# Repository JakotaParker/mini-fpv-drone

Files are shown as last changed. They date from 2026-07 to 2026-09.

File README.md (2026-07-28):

# Mini 3-Inch FPV Drone

A documented engineering project to design, manufacture, assemble, configure, and test a mini 3-inch FPV quadcopter with a primarily 3D-printed airframe.

## Current Project Status

**Phase:** Step 1 — Define the Project  
**Current revision:** Frame V1  
**Frame status:** CAD model completed in Onshape  
**Manufacturing status:** Full Frame V1 print has not yet been completed and validated  
**Flight status:** Not assembled or flight-tested  

Frame V1 must be treated as an **unvalidated prototype** until it passes dimensional inspection, component-fit checks, structural checks, and a complete print test.

## Primary Objectives

- Design a functional 3-inch FPV quadcopter.
- Use an Ender 3 V2 to prototype the frame.
- Learn CAD design, additive manufacturing, electronics integration, soldering, Betaflight configuration, and flight testing.
- Maintain professional engineering documentation throughout the build.
- Create a platform that can later support more advanced embedded-systems and autonomous-drone projects.

## Initial System Architecture

```mermaid
flowchart TD
    Pilot[Pilot] --> Radio[Radio Transmitter]
    Radio --> RX[ELRS Receiver]
    RX --> FC[Flight Controller]
    FC --> ESC[Electronic Speed Controllers]
    ESC --> Motors[Four Brushless Motors]
    Battery[LiPo Battery] --> ESC
    Battery --> FC
    FC --> VTX[Video Transmitter]
    Camera[FPV Camera] --> VTX
    VTX --> Goggles[FPV Goggles]
    Frame[3D-Printed Frame] --> Motors
    Frame --> FC
    Frame --> Battery
    Frame --> Camera
```

## Repository Structure

- `docs/` — project definition, requirements, architecture, BOM, build log, and test plan
- `cad/` — exported CAD revisions, drawings, screenshots, and Onshape links
- `electronics/` — wiring diagrams, pin maps, and electronics integration notes
- `firmware/` — Betaflight configuration backups and firmware notes
- `manufacturing/` — slicer settings, print profiles, and manufacturing observations
- `tests/` — dimensional, structural, electronics, bench, and flight-test records
- `media/` — labeled photos and videos used in the documentation

## Versioning Rules

- Use `Frame V1`, `Frame V2`, and so on for major geometry revisions.
- Never overwrite an old validated or tested design.
- Record the reason for every revision in `CHANGELOG.md`.
- Export both `.STL` and `.STEP` when a CAD revision is ready for review.
- Use filenames such as:
  - `frame-v1.stl`
  - `frame-v1.step`
  - `frame-v1-top.png`
  - `frame-v1-print-test-2026-07-22.md`

# Current Project Status

## Completed

- Initial project planning
- System architecture
- Custom Frame V1
- Mini prototype printed
- Component compatibility verification
- Final BOM selected
- All components ordered

## Current Phase

Mechanical Integration (Frame V2)

## Next Milestones

- Receive components
- Measure actual dimensions
- Update Onshape
- Print Frame V2
- Assemble electronics
- First power-on
- Configure Betaflight
- Maiden hover

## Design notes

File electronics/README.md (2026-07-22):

# Electronics

Store the electrical architecture and wiring documentation here.

## Planned Files

- `wiring-diagram.md`
- `flight-controller-pin-map.md`
- `power-budget.md`
- `soldering-checklist.md`
- `continuity-test-log.md`

## Safety Rule

Do not install propellers during soldering, continuity testing, firmware configuration, receiver setup, or motor-direction testing.

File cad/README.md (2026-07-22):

# CAD Directory

Store exported design files by revision. Onshape remains the cloud CAD source of truth, while GitHub stores reviewable exports and revision documentation.

## Recommended Revision Structure

- `frame-v1/`
- `frame-v2/`
- `camera-mount-v1/`
- `antenna-mount-v1/`

Each revision folder should contain:

- Onshape link
- STL export
- STEP export
- Screenshots
- Critical dimensions
- Known issues
- Test status

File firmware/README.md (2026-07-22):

# Firmware

Use this directory for Betaflight configuration records.

## Save

- Flight-controller target and firmware version
- Date flashed
- Port configuration
- Receiver protocol
- Modes
- Motor protocol
- Motor order and direction
- Failsafe settings
- OSD settings
- VTX table
- CLI backups

## Suggested Filenames

- `betaflight-backup-before-setup-YYYY-MM-DD.txt`
- `betaflight-backup-first-hover-YYYY-MM-DD.txt`
- `betaflight-settings.md`

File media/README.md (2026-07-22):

# Media

Store compressed, labeled documentation images here.

## Naming Examples

- `2026-07-22-frame-v1-onshape-isometric.png`
- `2026-07-25-frame-v1-print-failure.jpg`
- `2026-07-27-frame-v1-motor-fit.jpg`

Avoid committing large raw videos directly to GitHub. Upload large videos elsewhere and add a link in the relevant build-log or test file.

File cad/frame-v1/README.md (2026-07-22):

# Frame V1

## Status

**CAD complete — full print not yet validated**

## Onshape Document

Paste the share link here:

`https://cad.onshape.com/documents/b07e0402ccf89ec4abb02c89/w/8f168de043c1d81def7e68bb/e/86ea48fc1ecbca987625806d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`

Use a view-only public or appropriately shared link. Do not expose private account information.

## Expected Files

- `frame-v1.stl` 
- `frame-v1.step`
- `frame-v1-top.png`
- `frame-v1-bottom.png`
- `frame-v1-isometric.png`

## Design Intent

Frame V1 is the first physical prototype for a mini 3-inch FPV quadcopter. It is intended to validate:

- Overall geometry
- Printability
- Arm stiffness
- Motor mounting
- Electronics mounting
- Camera placement
- Battery placement
- Propeller clearance
- Wiring access

## Validation Status

| Check | Status | Notes |
|---|---|---|
| CAD geometry completed | COMPLETE | Onshape model exists |
| STL exported | COMPLETE | |
| STEP exported | COMPLETE | |
| Full print completed | Not tested | |
| Dimensions measured | Not tested | |
| Motor fit checked | Not tested | |
| Electronics fit checked | Not tested | |
| Propeller clearance checked | Not tested | |
| Structural test completed | Not tested | |
| Flight tested | Not tested | |

## Known Risks

- PLA+ may be adequate for fit testing but may not be the final flight material.
- Mounting dimensions have not yet been physically validated.
- Arm stiffness and crash durability are unknown.
- Long print duration requires active supervision and printer-safety precautions.

## Frame V1 Specifications

- Propeller class: 3 inch
- Overall Length:
- Overall Width:
- Frame Thickness:
- Arm Width:
- Motor mounting-hole spacing:
- Flight-controller mounting-hole spacing:
- Estimated frame weight:
- Battery mounting location:
- Camera mounting location:

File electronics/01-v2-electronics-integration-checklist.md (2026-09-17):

# V2 Drone — Electronics Integration Checklist

Use this checklist to guide the V2 drone from completed frame to first powered flight.

---

## Phase 1 — Electronics Planning

- [x] Create an electronics assembly sequence before soldering anything
- [x] Review the exact SpeedyBee F405 AIO wiring and pad diagram
- [x] Identify the connection point for each subsystem:
  - [x] Motor 1
  - [x] Motor 2
  - [x] Motor 3
  - [x] Motor 4
  - [x] Battery / XT30
  - [x] Capacitor
  - [x] Receiver
  - [x] FPV camera
  - [x] TX800 VTX
  - [ ] Buzzer, if used
- [x] Identify the required power rails and signals:
  - [x] VBAT
  - [x] 5V
  - [x] Ground
  - [x] UART TX
  - [x] UART RX
  - [x] Video signal
  - [x] Motor phases
- [x] Create the complete electrical wiring diagram
- [x] Label every wire and destination pad
- [x] Create a physical wire-routing plan for the V2 frame
- [x] Decide the electronics stack / component placement order
- [ ] Confirm USB access after the AIO is installed
- [ ] Confirm planned wire paths cannot reach the propellers
- [ ] Save the wiring diagram to the GitHub repository

---

## Phase 2 — Parts Arrival and Unboxing

### Documentation Setup

- [x] Set up camera / Meta glasses before opening packages
- [X] Record all packages together
- [x] Record the unboxing of each major component
- [x] Capture close-up footage of each electronic component
- [x] Capture the V2 frame beside the real components
- [x] Photograph component labels, model numbers, and connectors

### Initial Inspection

- [X] Inspect every package for shipping damage
- [x] Confirm each received component matches the ordered model
- [x] Confirm all expected accessories and cables are included
- [x] Do not solder anything yet

---

## Phase 3 — Physical Component Verification

Measure every component with digital calipers and compare the measurements against the CAD envelopes and manufacturer specifications.

### Motors

- [x] Measure motor diameter
- [x] Measure motor height
- [x] Measure shaft diameter
- [x] Measure mounting-hole spacing
- [x] Verify mounting screw size
- [x] Verify motor screws do not extend into the motor windings

### SpeedyBee F405 AIO

- [x] Measure board length
- [x] Measure board width
- [x] Measure board thickness / installed height
- [x] Measure mounting-hole spacing
- [x] Measure mounting-hole diameter
- [x] Verify USB connector location
- [x] Verify battery pads
- [x] Verify motor pads
- [x] Verify UART pads
- [x] Verify video pads

### RunCam Nano 4

- [x] Measure camera width
- [x] Measure camera height
- [x] Measure camera depth
- [x] Verify cable exit direction
- [x] Verify lens clearance

### SpeedyBee TX800 VTX

- [x] Measure board length
- [x] Measure board width
- [x] Measure board thickness
- [x] Verify antenna connector orientation
- [x] Verify power / signal connection locations

### Receiver

- [x] Measure receiver length
- [x] Measure receiver width
- [x] Measure receiver thickness
- [x] Verify antenna arrangement
- [x] Verify wire / pad orientation

### Battery

- [x] Measure battery length
- [x] Measure battery width
- [x] Measure battery height
- [x] Measure battery weight
- [x] Verify XT30 lead length
- [x] Verify battery orientation in the frame

### Other Components

- [x] Verify propeller diameter
- [x] Verify propeller shaft / mounting interface
- [x] Measure antenna dimensions
- [x] Verify capacitor dimensions
- [x] Verify hardware and screw dimensions

### Documentation

- [x] Update `07-component-inventory.md`
- [x] Change verified measurements to **Physically Verified**
- [x] Record any differences between listed and measured dimensions
- [x] Photograph caliper measurements where useful

---

## Phase 4 — V2 Frame Fit Test

Install or position every component without permanent wiring.

### Motors and Propulsion

- [x] Mount all four motors
- [x] Verify motor-hole alignment
- [x] Verify screw length
- [x] Temporarily install props or use prop envelopes to verify clearance
- [x] Check full propeller sweep

### Electronics

- [x] Position the AIO
- [x] Position the FPV camera
- [x] Position the TX800
- [x] Position the receiver
- [x] Position the antenna
- [x] Position the capacitor
- [x] Position the battery

### Clearance Checks

- [x] Check propeller clearance
- [x] Check USB-port accessibility
- [x] Check battery-connector routing
- [x] Check antenna clearance
- [x] Check camera field of view
- [x] Check camera lens protection
- [ ] Check that motor wires can reach the AIO
- [x] Check receiver wire routing
- [ ] Check VTX wire routing
- [x] Check camera wire routing
- [ ] Check that no wire can enter the propeller sweep
- [ ] Check that components do not interfere with one another

### Documentation

- [x] Photograph the complete mock assembly
- [x] Record any fitment problems
- [x] Update CAD if required
- [ ] Update GitHub documentation with fit-test results

---

## Phase 5 — TPU Mount Verification and Printing

### Before Printing

- [x] Compare each TPU CAD model against real component measurements
- [x] Correct dimensions if necessary
- [x] Add appropriate TPU fit clearance / tolerance
- [x] Confirm screw holes and slots align
- [x] Confirm wire-routing openings remain accessible

### TPU Print Testing

- [ ] Slice the smallest / fastest TPU mount first
- [x] Run a TPU calibration print
- [ ] Inspect print quality
- [ ] Test-fit the component
- [x] Adjust CAD if necessary
- [ ] Reprint the test mount if required

### Final TPU Parts

- [x] Print battery mount
- [x] Print camera mount, if TPU
- [x] Print antenna mount
- [x] Print receiver mount, if used
- [x] Print VTX mount / retention part, if used
- [x] Test-fit every finished TPU part

### Documentation

- [x] Record TPU slicer settings
- [ ] Photograph or record TPU printing
- [ ] Document fit adjustments
- [ ] Export updated STL / STEP files to GitHub

---

## Phase 6 — Electronics Bench Test

Before permanently installing or soldering the complete system:

### Inspection

- [x] Inspect AIO for visible damage
- [ ] Inspect motor wires and windings
- [x] Inspect receiver
- [x] Inspect TX800
- [x] Inspect camera
- [ ] Inspect antenna connectors
- [ ] Inspect battery connector

### Flight Controller

- [ ] Connect the AIO to the computer using a known-good USB data cable
- [ ] Verify the flight controller powers from USB
- [ ] Verify Betaflight Configurator detects the flight controller
- [ ] Record the current firmware version
- [ ] Save a backup / dump of the original Betaflight configuration
- [ ] Verify board orientation in Betaflight

### Peripheral Planning

- [ ] Confirm receiver protocol
- [ ] Confirm required UART for receiver
- [ ] Confirm VTX control method
- [ ] Confirm camera voltage requirement
- [ ] Confirm receiver voltage requirement
- [ ] Confirm TX800 voltage requirement
- [ ] Compare all requirements against the wiring diagram

- [ ] Do not connect the LiPo until battery wiring has been completed and inspected

---

## Phase 7 — Soldering

Keep propellers removed during the entire electronics setup process.

### Preparation

- [ ] Prepare soldering iron
- [ ] Prepare solder and flux
- [ ] Prepare wire cutters and wire strippers
- [ ] Prepare heat shrink
- [ ] Prepare multimeter
- [ ] Prepare smoke stopper
- [ ] Secure the board in a PCB holder / helping hands
- [ ] Tin wires before attaching them
- [ ] Tin pads as appropriate

### Suggested Soldering Order

1. [ ] Battery lead / XT30
2. [ ] Capacitor
3. [ ] Motor 1
4. [ ] Motor 2
5. [ ] Motor 3
6. [ ] Motor 4
7. [ ] Receiver
8. [ ] FPV camera
9. [ ] TX800 VTX
10. [ ] Buzzer / remaining accessories

### After Each Subsystem

- [ ] Inspect solder joints
- [ ] Check for solder bridges
- [ ] Verify polarity
- [ ] Verify correct pad selection
- [ ] Perform continuity checks where appropriate
- [ ] Check wire strain relief
- [ ] Photograph completed connections
- [ ] Update wiring documentation if routing changes

### Before First LiPo Connection

- [ ] Perform final visual inspection
- [ ] Check XT30 polarity
- [ ] Check VBAT-to-GND for an unintended short
- [ ] Verify capacitor polarity
- [ ] Verify every powered peripheral's polarity
- [ ] Remove propellers
- [ ] Connect LiPo through a smoke stopper
- [ ] Verify normal startup
- [ ] Disconnect immediately if the smoke stopper indicates a fault

---

## Phase 8 — Betaflight Configuration

### Flight Controller

- [ ] Confirm FC orientation
- [ ] Verify accelerometer response
- [ ] Verify gyro response
- [ ] Calibrate accelerometer if appropriate

### Receiver

- [ ] Configure receiver UART
- [ ] Configure receiver protocol
- [ ] Bind transmitter to receiver
- [ ] Verify channel inputs
- [ ] Verify channel mapping
- [ ] Set arm switch
- [ ] Configure desired flight modes
- [ ] Configure and test failsafe

### Motors

**Propellers must remain removed.**

- [ ] Verify motor 1 assignment
- [ ] Verify motor 2 assignment
- [ ] Verify motor 3 assignment
- [ ] Verify motor 4 assignment
- [ ] Verify each motor spins
- [ ] Verify motor direction
- [ ] Correct motor direction if required

### FPV System

- [ ] Verify camera powers correctly
- [ ] Verify video feed
- [ ] Configure VTX
- [ ] Verify VTX channel / band / power configuration
- [ ] Verify antenna is connected before transmitting

### Configuration Backup

- [ ] Save final Betaflight configuration
- [ ] Export CLI `diff all`
- [ ] Store configuration backup in GitHub documentation

---

## Phase 9 — Final Assembly

- [ ] Install TPU mounts
- [ ] Secure AIO
- [ ] Secure receiver
- [ ] Secure TX800
- [ ] Secure FPV camera
- [ ] Secure antenna
- [ ] Secure capacitor
- [ ] Route motor wires
- [ ] Route receiver wires
- [ ] Route camera / VTX wires
- [ ] Add heat shrink where needed
- [ ] Add strain relief where needed
- [ ] Secure battery lead
- [ ] Verify USB port remains accessible
- [ ] Verify antenna cannot enter propeller sweep
- [ ] Verify battery cannot move into propeller sweep
- [ ] Verify no wire can touch a propeller
- [ ] Verify no screw is loose
- [ ] Install battery
- [ ] Measure final all-up weight
- [ ] Photograph the completed V2 drone

---

## Phase 10 — First Flight Preparation

### Final Safety Inspection

- [ ] Check all frame screws
- [ ] Check all motor screws
- [ ] Check electronics mounting
- [ ] Inspect solder joints
- [ ] Inspect battery lead
- [ ] Inspect antenna
- [ ] Verify receiver connection
- [ ] Verify FPV video
- [ ] Perform receiver range check
- [ ] Perform failsafe test
- [ ] Verify motor order
- [ ] Verify motor direction
- [ ] Verify propeller orientation

### Propeller Installation

Only install propellers after all motor and failsafe testing is complete.

- [ ] Install correct propeller on Motor 1
- [ ] Install correct propeller on Motor 2
- [ ] Install correct propeller on Motor 3
- [ ] Install correct propeller on Motor 4
- [ ] Verify propeller orientation one final time

### First Hover

- [ ] Select a safe open test area
- [ ] Power the drone
- [ ] Verify receiver and video link
- [ ] Arm from a safe distance
- [ ] Perform a short low-altitude hover
- [ ] Land
- [ ] Disarm
- [ ] Disconnect battery
- [ ] Inspect the drone after the hover
- [ ] Check motor temperatures
- [ ] Check electronics mounting
- [ ] Check frame and TPU mounts
- [ ] Record any problems or changes required

---

## Phase 11 — Engineering Documentation

- [ ] Update `07-component-inventory.md`
- [ ] Add final wiring diagram
- [ ] Add physical electronics layout
- [ ] Add soldering / wiring photos
- [ ] Record final component locations
- [ ] Record final wire-routing decisions
- [ ] Record Betaflight configuration
- [ ] Record TPU settings
- [ ] Record completed drone weight
- [ ] Document problems encountered
- [ ] Document design changes made after physical testing
- [ ] Update V2 CAD / STEP / STL files if required
- [ ] Commit completed V2 integration documentation to GitHub

---

## Build Status

- [ ] Mechanical V2 frame complete
- [ ] Components physically verified
- [ ] TPU mounts complete
- [ ] Wiring diagram complete
- [ ] Electronics bench-tested
- [ ] Soldering complete
- [ ] First power-up successful
- [ ] Betaflight configured
- [ ] Final assembly complete
- [ ] First hover successful
- [ ] V2 documentation complete

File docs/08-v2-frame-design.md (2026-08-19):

# V2 Frame Design

## Overview

V2 is the first frame revision designed around the actual purchased FPV hardware.

Unlike V1, which was primarily used to establish the basic frame geometry and test the 3D-printing workflow, V2 uses a parametric CAD workflow based on measured component dimensions, mounting patterns, and clearance requirements.

---

## Design Goals

The primary goals for V2 are:

- Design the frame around the actual purchased components
- Maintain clearance for 3-inch propellers
- Create accurate motor and AIO mounting patterns
- Maintain a centralized battery and flight-controller layout
- Provide space for the camera, VTX, receiver, wiring, and antennas
- Keep major dimensions controlled through master parameters
- Make future design changes propagate through the CAD model efficiently

---

## Master Parameter System

A Variable Studio was created in Onshape to control major frame and component dimensions.

Important frame parameters include:

- Wheelbase
- Motor center positions
- Arm width
- Frame center dimensions
- Frame thickness
- Motor pad diameter
- Propeller diameter
- General/component clearances

Component-specific parameters were also added for:

- SpeedyBee 1404 motors
- SpeedyBee F405 AIO
- Propellers

This allows important dimensions to be changed from a central parameter table instead of manually modifying individual sketches.

---

## Component Envelope Models

Simplified envelope models were created to represent the physical space occupied by the purchased components.

Models created:

- `Motor_1404_Envelope`
- `AIO_Envelope`
- `Camera_Envelope`
- `Battery_Envelope`
- `Receiver_Envelope`
- `VTX_Envelope`

These models intentionally omit unnecessary electronic detail and are used for packaging and interference checks.

---

## Master Layout

A master layout was created before redesigning the physical frame.

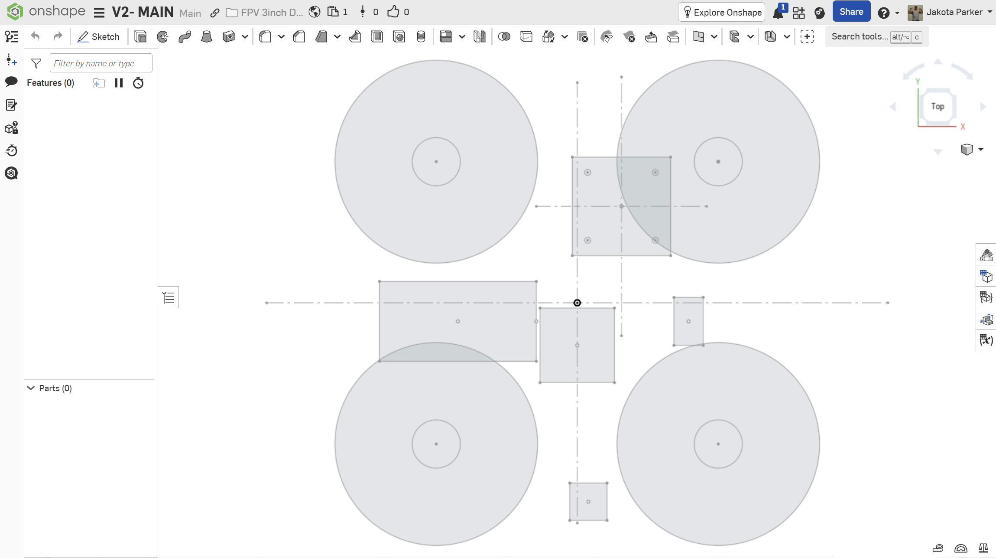
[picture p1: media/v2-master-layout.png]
Master Layout

### Motor Layout

The motor layout defines:

- Four motor center locations
- 150 mm wheelbase
- Motor pad locations
- 3-inch propeller sweep envelopes
- Propeller-to-propeller clearance

### Electronics Layout

The electronics layout was used to estimate the required central packaging area for:

- Flight controller
- Battery
- Camera
- VTX
- ELRS receiver

---

## V2 Frame Geometry

The V2 frame was created using the master layout as a reference.

Current frame features include:

- Central electronics body
- Four integrated arms
- Four circular motor pads
- Motor mounting holes
- AIO mounting holes

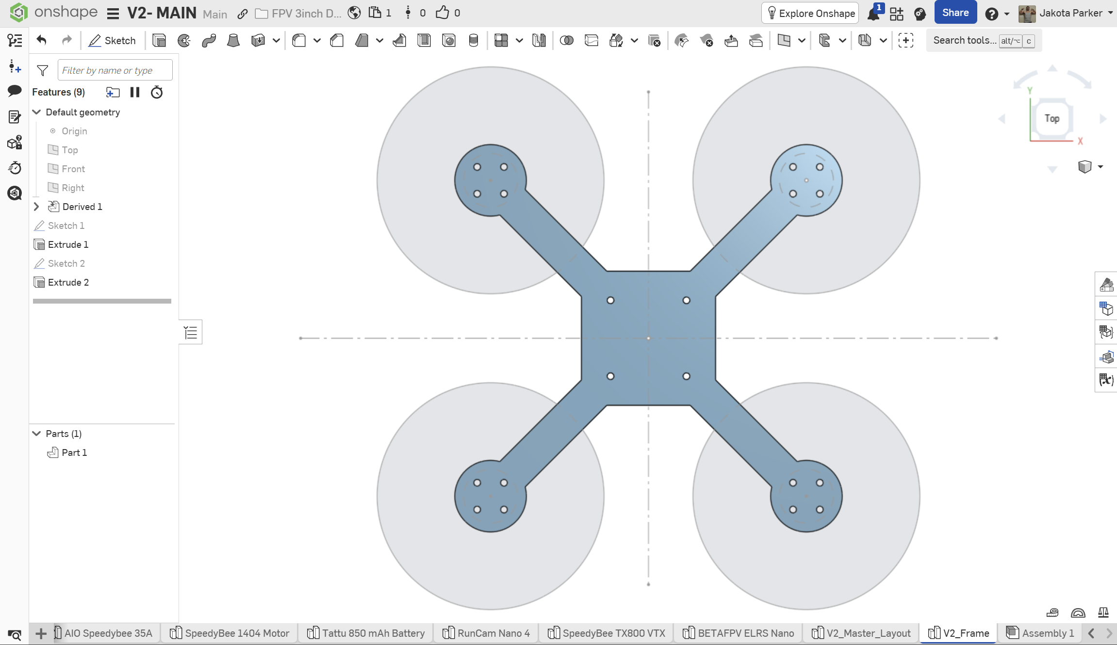
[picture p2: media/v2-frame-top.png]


### Motor Mounts

The SpeedyBee 1404 motors use a 9 mm square mounting pattern with M2 hardware.

The frame uses clearance holes rather than printed threads. The mounting screws pass through the printed frame and thread directly into the motor.

Motor screw length will be physically verified after the motors arrive to prevent screws from contacting the motor windings.

### AIO Mount

The SpeedyBee F405 AIO uses a:

- 25.5 mm × 25.5 mm mounting pattern
- Four mounting locations

The mounting pattern is centered around the frame origin.

---

## Assembly Packaging Study

A preliminary assembly was created to verify that the purchased components can physically fit within the V2 architecture.

Components currently represented in the assembly:

- V2 frame
- 4 × SpeedyBee 1404 motors
- 4 × 3-inch propeller envelopes
- SpeedyBee F405 AIO
- Tattu 4S 850 mAh battery
- RunCam Nano 4 camera
- SpeedyBee TX800 VTX
- BETAFPV ELRS Nano receiver

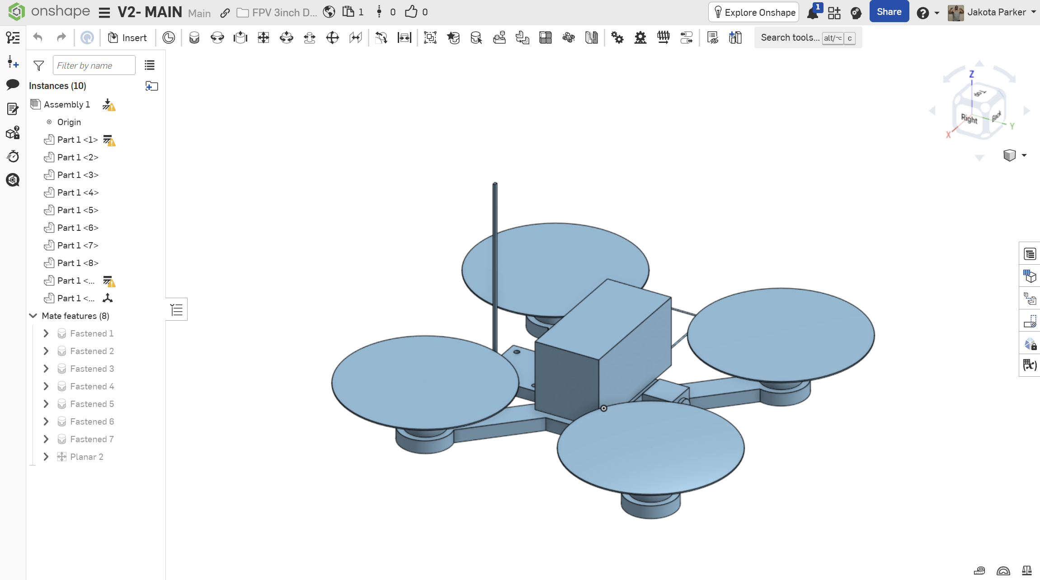
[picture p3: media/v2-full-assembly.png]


### Preliminary Component Placement

**Battery**

The battery is positioned above the central electronics area near the aircraft center of mass.

**AIO**

The AIO is centered on the frame using its 25.5 × 25.5 mm mounting pattern.

**Camera**

The camera is positioned at the front-center of the aircraft between the front arms. The final mount will allow an upward FPV camera angle.

**TX800**

The VTX is positioned toward the rear of the aircraft to provide a short antenna routing path.

**ELRS Receiver**

The receiver is positioned in available space near the rear electronics area. Because of its low mass and small dimensions, it will not drive the overall frame dimensions.

---

## Preliminary Clearance Verification

The assembly was used to check:

- [x] Propeller-to-propeller clearance
- [x] Propeller-to-frame clearance
- [x] Motor mounting alignment
- [x] AIO fit
- [x] Battery footprint
- [x] Camera packaging
- [x] VTX packaging
- [x] Receiver packaging
- [ ] Motor wire routing
- [ ] Camera cable routing
- [ ] VTX wiring
- [ ] Receiver wiring
- [ ] Battery lead routing
- [ ] USB-C access
- [ ] Final antenna routing

---

## Remaining V2 Design Work

Before printing V2:

- [ ] Verify physical component dimensions when parts arrive
- [x] Add battery strap slots
- [x] Design camera mounting interface
- [x] Design VTX retention/mounting
- [x] Design antenna retention
- [x] Determine receiver retention method
- [ ] Verify AIO standoff/grommet requirements
- [ ] Verify motor screw length
- [x] Add structural fillets
- [x] Review arm-to-center stress concentrations
- [x] Review arm-to-motor-pad transitions
- [x] Evaluate frame thickness and weight
- [ ] Export V2 STEP
- [ ] Export V2 STL
- [x] Print V2 prototype
- [ ] Physically test component fit

---

## Design Status

**V2 Status:** CAD packaging / mechanical design in progress

The major purchased components have been represented in the assembly and preliminary packaging indicates that the current frame architecture is viable.

The next stage is to design the component retention features and refine the frame for its first V2 prototype print.

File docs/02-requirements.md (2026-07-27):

# 02 — Requirements

Use `MUST`, `SHOULD`, and `MAY` to distinguish required, preferred, and optional features.

## Airframe Requirements

- **AF-001:** The frame MUST fit within the Ender 3 V2 build area.
- **AF-002:** The frame MUST support four motors intended for 3-inch propellers.
- **AF-003:** The design MUST provide adequate propeller-to-frame clearance.
- **AF-004:** The design MUST provide a defined flight-controller mounting pattern.
- **AF-005:** The design MUST provide a secure battery-retention method.
- **AF-006:** The design MUST keep wiring away from propeller paths.
- **AF-007:** The design SHOULD allow damaged components to be replaced without destroying the frame.
- **AF-008:** The frame SHOULD include accessible USB and battery connections.
- **AF-009:** The frame SHOULD include replaceable camera or antenna mounts.

## Manufacturing Requirements

- **MF-001:** Frame V1 MUST complete a supervised full print before being approved for assembly.
- **MF-002:** Print settings MUST be recorded for every test.
- **MF-003:** Failed prints MUST include a short failure description and corrective action.
- **MF-004:** Critical mounting dimensions MUST be measured after printing.
- **MF-005:** The prototype SHOULD print without requiring excessive support material.

## Electronics Requirements

- **EL-001:** The power system MUST be compatible with the selected battery voltage.
- **EL-002:** The ESC current rating MUST provide appropriate margin for the selected motors and propellers.
- **EL-003:** The receiver MUST be compatible with the selected radio protocol.
- **EL-004:** The flight controller MUST provide the required UARTs and motor outputs.
- **EL-005:** All solder joints MUST be visually inspected before power is applied.
- **EL-006:** Initial power-up MUST use a smoke stopper.
- **EL-007:** Continuity MUST be checked before connecting a LiPo battery.

## Firmware Requirements

- **FW-001:** A Betaflight configuration backup MUST be saved before major configuration changes.
- **FW-002:** Receiver input MUST be verified without propellers installed.
- **FW-003:** Motor order and direction MUST be verified without propellers installed.
- **FW-004:** Failsafe behavior MUST be configured and tested.
- **FW-005:** Arming controls MUST be deliberately assigned and documented.

## Test Requirements

- **TS-001:** Propellers MUST remain removed during electronics bench testing.
- **TS-002:** The first hover test MUST occur in a controlled open area.
- **TS-003:** A preflight inspection MUST be completed before every test flight.
- **TS-004:** Damage, instability, overheating, or signal loss MUST stop the test.

## Mechanical Requirements

- The frame shall support 3-inch propellers without overlap.
- The frame shall support a 25.5 × 25.5 mm AIO mounting pattern.
- The center section shall provide clearance for a 33 × 33 × 8 mm AIO.
- The motor mounts shall support a 9 × 9 mm M2 pattern.
- The frame shall support a 14 mm nano FPV camera.
- The frame shall include mounting provisions for a 15 mm battery strap.
- The design shall provide safe routing for the VTX antenna, ELRS antenna, and XT30 lead.
- Target all-up weight shall be 250 g or less.

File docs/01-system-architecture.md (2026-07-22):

# 01 — System Architecture

## Functional Architecture

```mermaid
flowchart LR
    TX[Radio Transmitter] --> RX[ELRS Receiver]
    RX --> FC[Flight Controller]
    IMU[Gyroscope / Accelerometer] --> FC
    FC --> ESC[4-in-1 ESC or AIO ESC Section]
    ESC --> M1[Motor 1]
    ESC --> M2[Motor 2]
    ESC --> M3[Motor 3]
    ESC --> M4[Motor 4]

    CAM[FPV Camera] --> VTX[Video Transmitter]
    VTX --> GOG[FPV Goggles]

    BAT[LiPo Battery] --> ESC
    ESC --> FC
    FC --> RX
    FC --> CAM
    FC --> VTX
```

## Physical Architecture

### Airframe
- Main frame
- Motor arms
- Electronics mounting area
- Camera mount
- Battery mounting area
- Antenna mounting provisions
- Fasteners and standoffs

### Propulsion
- Four brushless motors
- Four 3-inch propellers
- ESC system
- LiPo battery

### Flight Control
- Flight controller
- IMU
- Betaflight firmware
- Receiver connection
- Motor-output connections

### FPV System
- FPV camera
- Video transmitter
- VTX antenna
- FPV goggles or receiver display

### Ground Control
- ExpressLRS-compatible radio transmitter
- Betaflight Configurator computer
- Battery charger
- Smoke stopper
- Multimeter

## Interface Table

| Source | Destination | Interface | Status |
|---|---|---|---|
| Radio transmitter | ELRS receiver | RF control link | TBD |
| ELRS receiver | Flight controller | UART/CRSF | TBD |
| Flight controller | ESC | Motor signals / onboard AIO connection | TBD |
| ESC | Motors | Three phase wires per motor | TBD |
| FPV camera | Flight controller or VTX | Analog video | TBD |
| Flight controller | VTX | Video and optional control UART | TBD |
| LiPo battery | ESC/AIO | Main battery power | TBD |
| Flight controller | Betaflight computer | USB | Planned |

## Architecture Decision Record

For every major component or architecture choice, record:

- Decision
- Options considered
- Selection criteria
- Final choice
- Reason
- Risks
- Date

## Preliminary Component Placement

- Flight controller / AIO: center of frame
- Battery: TBD, top-mounted or bottom-mounted
- FPV camera: front
- ELRS receiver: rear or side of electronics stack
- Video transmitter: rear or above flight controller
- VTX antenna: rear, clear of propellers
- Battery lead: accessible while remaining clear of propellers
- USB port: must remain accessible after assembly

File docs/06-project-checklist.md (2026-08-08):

# Mini FPV Drone V1 Project Checklist

## Planning

- [x] Project defined
- [x] GitHub repository created
- [x] Requirements documented
- [x] Initial frame designed
- [x] Component compatibility verified
- [x] Total BOM cost calculated
- [x] Remaining specifications filled in

---

## CAD

- [x] Frame V1 designed
- [x] Frame V1 prototype printed
- [x] Frame V2 updated with electronics
- [x] Camera mount designed
- [x] Battery strap slots added
- [x] Mounting holes finalized

---

## Ordering

- [x] Components ordered
- [ ] Components received
- [ ] Inventory checked

---

## Assembly

- [ ] Motors installed
- [ ] AIO mounted
- [ ] Receiver soldered
- [ ] VTX soldered
- [ ] Camera installed
- [ ] Smoke stopper test passed

---

## Firmware

- [ ] Betaflight installed
- [ ] ESC firmware verified
- [ ] ELRS bound
- [ ] VTX configured
- [ ] Modes configured
- [ ] Failsafe tested

---

## Flight Testing

- [ ] Bench test
- [ ] Motor direction verified
- [ ] Hover test
- [ ] Maiden flight
- [ ] PID tuning
- [ ] Final validation

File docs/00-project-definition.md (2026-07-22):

# 00 — Project Definition

## Project Name

Mini 3-Inch FPV Drone

## Problem Statement

Design and build a compact FPV quadcopter using a custom 3D-printed frame while developing practical skills in CAD, additive manufacturing, electronics, soldering, flight-controller configuration, troubleshooting, and technical documentation.

## Mission

The first completed aircraft should be a manually piloted, line-of-sight and FPV-capable mini quadcopter that can take off, hover, maneuver, land, and survive normal beginner-level testing.

Autonomous capability is outside the first build scope, but the project should establish skills and architecture that can support later embedded-systems and autonomous-drone work.

## Scope

### Included in the Initial Build

- Custom 3D-printed frame
- Four brushless motors
- Flight controller
- Electronic speed-control system
- ExpressLRS receiver
- FPV camera
- Video transmitter
- Antenna
- LiPo battery
- Radio transmitter
- FPV goggles
- Betaflight setup
- Bench testing
- Controlled flight testing
- Engineering documentation

### Not Included in the Initial Build

- GPS navigation
- Autonomous waypoint flight
- Computer vision
- Payload delivery
- Long-range operations
- Military or weapon applications
- Fully optimized production-grade frame

## Current State

- Frame V1 CAD: complete in Onshape
- Full Frame V1 print: not yet validated
- Electronics layout: preliminary
- Final component selection: incomplete
- Wiring: not started
- Firmware configuration: not started
- Flight testing: not started

## Design Constraints

- Printer: Ender 3 V2
- Prototype material: PLA+
- Propeller class: 3 inch
- Frame should be printable on the available printer
- Components must remain accessible for repair
- Propellers must have adequate clearance
- Wiring must avoid propellers and sharp frame edges
- Battery and electronics must be securely retained
- The first aircraft should prioritize learning, repairability, and safe testing over maximum performance

## Success Criteria

The first build is successful when it can:

1. Complete a full frame print without a critical manufacturing defect.
2. Fit the selected motors, flight controller, camera, receiver, VTX, and battery-retention hardware.
3. Pass continuity and smoke-stopper testing.
4. Connect to Betaflight and correctly recognize the receiver and sensors.
5. Spin each motor in the correct direction under controlled bench conditions.
6. Arm safely.
7. Perform a stable takeoff, hover, controlled maneuver, and landing.
8. Produce enough documentation for the build to be reproduced or improved.

## Open Decisions

- Exact wheelbase
- Target all-up weight
- Motor size and KV
- Propeller type
- Battery cell count and capacity
- AIO versus separate flight-controller and ESC architecture
- Receiver model
- FPV camera and VTX
- Frame material after PLA+ prototyping
- Final budget

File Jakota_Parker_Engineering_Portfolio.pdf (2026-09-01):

### ENGINEERING PROJECT PORTFOLIO

# Jakota Parker

## Electrical Engineering | University of Maryland

# Custom 3-Inch FPV Quadcopter

## End-to-end hardware design, mechanical integration, electronics

planning, manufacturing, and flight-controller validation.

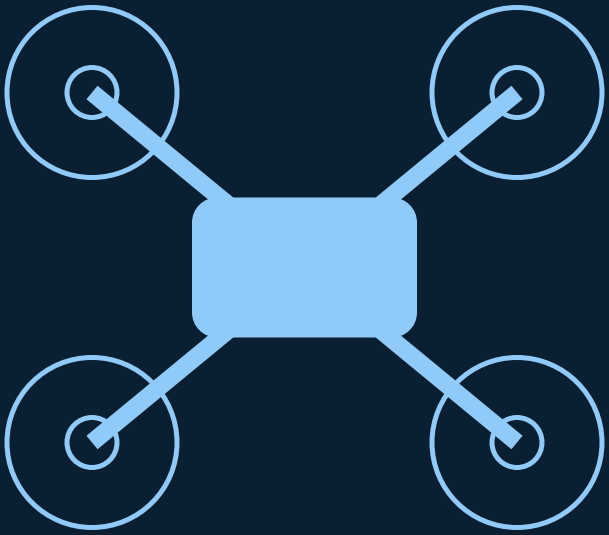
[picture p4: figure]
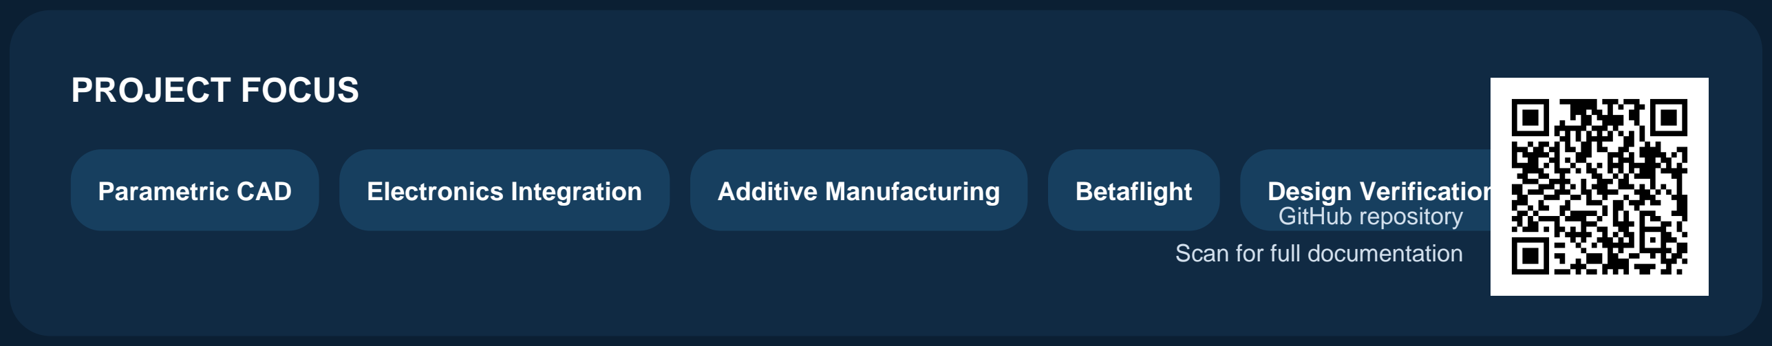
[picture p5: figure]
PROJECT FOCUS; Parametric CAD; Electronics Integration; Additive Manufacturing; Betaflight; Design Verification; GitHub repository Scan for full documentation

Prepared for Zipline - Electrical Engineering Internship

01 | SYSTEM THINKING

# Project Architecture

A compact aircraft treated as a complete electromechanical system, not just a frame.

Objective. Design, manufacture, assemble, configure, and test a custom 3-inch FPV quadcopter using a primarily 3D-printed airframe, while maintaining professional engineering documentation across CAD, electronics, manufacturing, firmware, and testing.

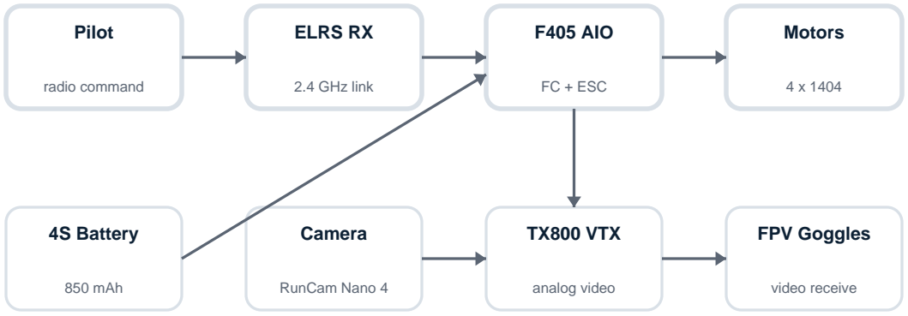
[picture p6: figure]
Pilot; radio command; ELRS RX; 2.4 GHz link; F405 AIO; FC + ESC; Motors; Camera; RunCam Nano 4; TX800 VTX; analog video; FPV Goggles; video receive; 4S Battery; 850 mAh

## Key engineering decisions

- Built the V2 architecture around the actual purchased electronics rather than forcing parts into a pre-existing frame.
- Used component envelopes and propeller sweep regions to perform packaging and interference checks before printing.
- Centralized major dimensions in an Onshape Variable Studio so changes propagate through the model.
- Kept the battery near the center of mass, the camera front-center, and the VTX rearward for shorter antenna routing.
Jakota Parker | 3-Inch FPV Quadcopter Engineering Portfolio | 2 / 6

02 | MECHANICAL DESIGN

# Parametric CAD + Packaging

V2 evolved from a geometric prototype into a hardware-driven design.

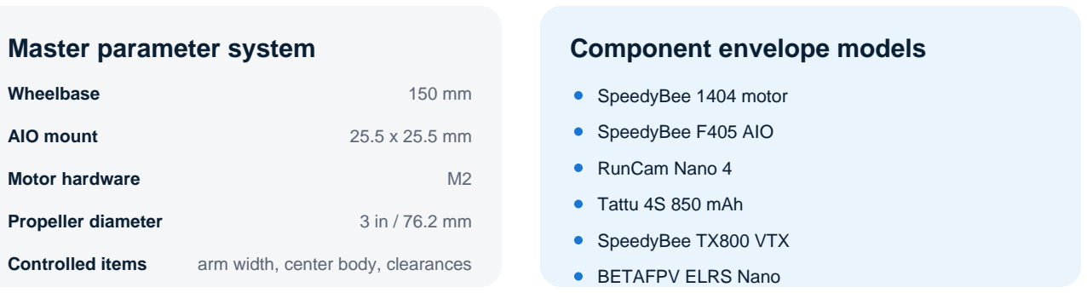
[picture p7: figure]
Master parameter system; Wheelbase; AIO mount; Motor hardware; Propeller diameter; Controlled items; arm width, center body, clearances; Component envelope models; SpeedyBee 1404 motor; SpeedyBee F405 AIO; RunCam Nano 4; Tattu 4S 850 mAh; SpeedyBee TX800 VTX; BETAFPV ELRS Nano

## Design-for-reality iteration

A major lesson was that nominal dimensions are not enough. Purchased components were measured with calipers and compared against CAD envelopes. Motor mounting geometry, screw length, USB access, camera clearance, VTX placement, receiver retention, battery support, and wire paths were treated as physical constraints to validate before flight.

### Mechanical verification

Caliper-based dimensions, hole spacing, clearance checks, fit testing, and print iteration.

### Manufacturing

Ender 3 V2 prototyping with PLA+ for the frame and TPU for compliant retention parts.

### Revision control

Separate V1/V2 design revisions, changelog discipline, and exported STL/STEP artifacts.

### ENGINEERING PRINCIPLE

Model what matters, measure what is uncertain, and keep geometry parametric enough to absorb change. This became the core V2 workflow.

Jakota Parker | 3-Inch FPV Quadcopter Engineering Portfolio | 3 / 6

03 | ELECTRICAL ENGINEERING

# Electronics Integration

Power, signaling, pad mapping, safe bring-up, and subsystem verification.

Subsystem | Selected hardware | Interface | Engineering concern
Flight controller | SpeedyBee F405 AIO V2 | USB / UART / video / ESC | pad map, orientation, power rails
Receiver | BETAFPV ELRS Nano | UART TX/RX | protocol, UART selection, antenna
Camera | RunCam Nano 4 | power + analog video | voltage, lens/cable clearance
Video TX | SpeedyBee TX800 | power + video + control | voltage, antenna routing, heat
Propulsion | 4 x 1404 4600KV | 3-phase motor outputs | motor order, direction, screw safety
Power | 4S 850 mAh LiPo | VBAT + GND | polarity, capacitor, short protection

## Safe bring-up sequence

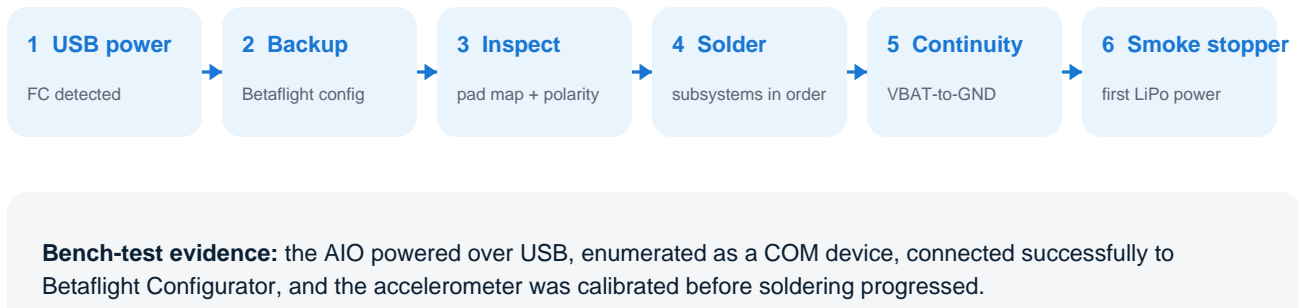
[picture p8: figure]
1 USB power; FC detected; 2 Backup; Betaflight config; 3 Inspect; pad map + polarity; 4 Solder; subsystems in order; 5 Continuity; VBAT-to-GND; 6 Smoke stopper; first LiPo power

Bench-test evidence: the AIO powered over USB, enumerated as a COM device, connected successfully to Betaflight Configurator, and the accelerometer was calibrated before soldering progressed.

Jakota Parker | 3-Inch FPV Quadcopter Engineering Portfolio | 4 / 6

04 | VERIFICATION

# Test, Debug, Iterate

The project is organized around evidence-based progression rather than “assemble and hope.”

1

Dimensional

Calipers vs CAD
envelopes

2

Mechanical

Frame + mount
fitment

3

Electrical

Continuity + polarity

4

Firmware

Betaflight + sensor
response

5

Actuation

Motor mapping +
direction

6

Safety

Failsafe + props-off
tests

7

Flight

Hover and post-flight
inspection

## Examples of engineering judgment

Fit before soldering Mock assembly and TPU retention checks happen before permanent electrical installation.

No props during setupPropellers stay removed through soldering, firmware configuration, receiver setup, and motor-direction testing.

Protect first power-on Visual inspection, polarity verification, continuity checks, and a smoke stopper precede first LiPo power.

Keep documentation liveIf routing or fit changes in hardware, the wiring/CAD documentation is updated to match the physical system.

## Current build status

Mechanical packaging, TPU mounts, and electronics bench validation are complete enough to move into soldering and subsystem integration. The next milestones are full wiring, continuity/smoke-stopper checks, receiver/VTX setup, motor validation, failsafe testing, and first controlled hover.

Jakota Parker | 3-Inch FPV Quadcopter Engineering Portfolio | 5 / 6

05 | ENGINEERING GROWTH

# What This Project Demonstrates

A small aircraft used as a platform for disciplined hardware engineering.

## Capabilities demonstrated

- System architecture - decomposed command, power, video, propulsion, and structural subsystems.
- CAD & packaging - built parametric layouts and component envelopes around real hardware.
- Electrical integration - mapped power rails, UARTs, video signals, motor outputs, and safe soldering order.
- Manufacturing - iterated PLA+ frame and TPU retention parts on an Ender 3 V2.
- Verification - used measurement, fit checks, continuity, staged power-on, and Betaflight validation.
- Technical documentation - maintained architecture, BOM, build logs, test plans, CAD revisions, and electronics checklists in GitHub.
- Debugging mindset - treated discrepancies as inputs for redesign rather than one-off fixes.
- Growth path - using this platform as a foundation for future embedded systems and autonomous UAV work. WHY THIS PROJECT MATTERS

This project forced me to work across mechanical and electrical boundaries: dimensions affect routing, routing affects maintainability, power choices affect thermal and safety constraints, and every physical change must still work with the flight-control stack. That systems-level interaction is the part of hardware engineering I want to keep developing professionally.

## Full engineering documentation

GitHub: JakotaParker / mini-fpv-drone

Includes CAD, build logs, BOM, electronics integration, manufacturing notes, firmware planning, and test documentation. github.com/JakotaParker/mini-fpv-drone

Jakota Parker | 3-Inch FPV Quadcopter Engineering Portfolio | 6 / 6

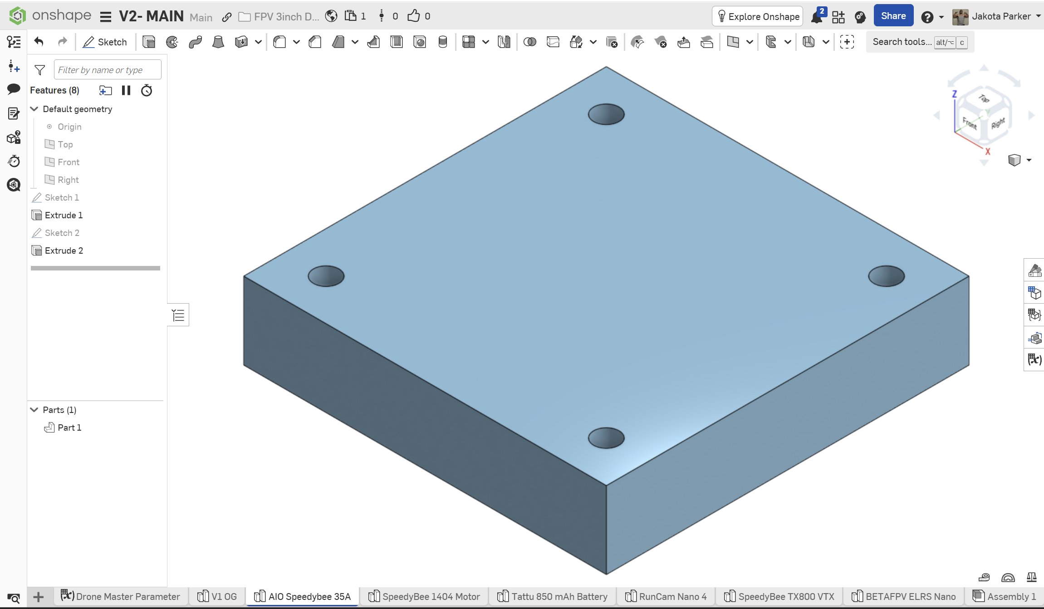
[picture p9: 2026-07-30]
media/7-30-26 SpeedyBee AIO Isometric.png

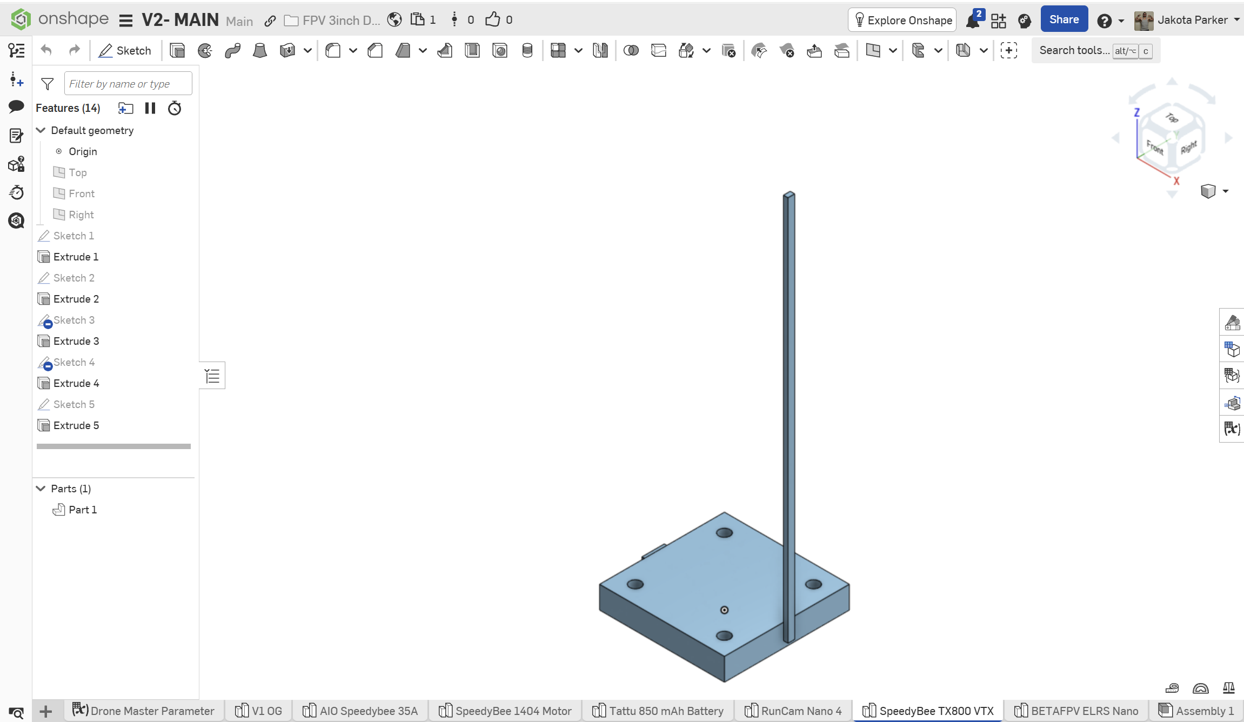
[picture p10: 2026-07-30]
media/7-30-26 SpeedyBee TX800 VTX Isometric.png

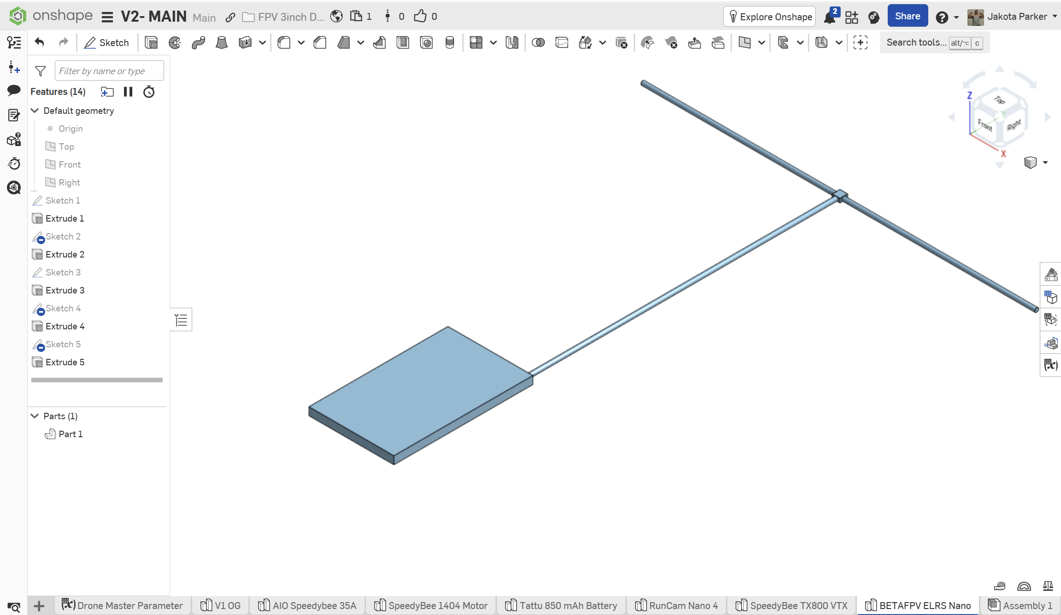
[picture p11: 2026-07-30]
media/7-30-26 BETAFPV ELRS Nano Isometric.png

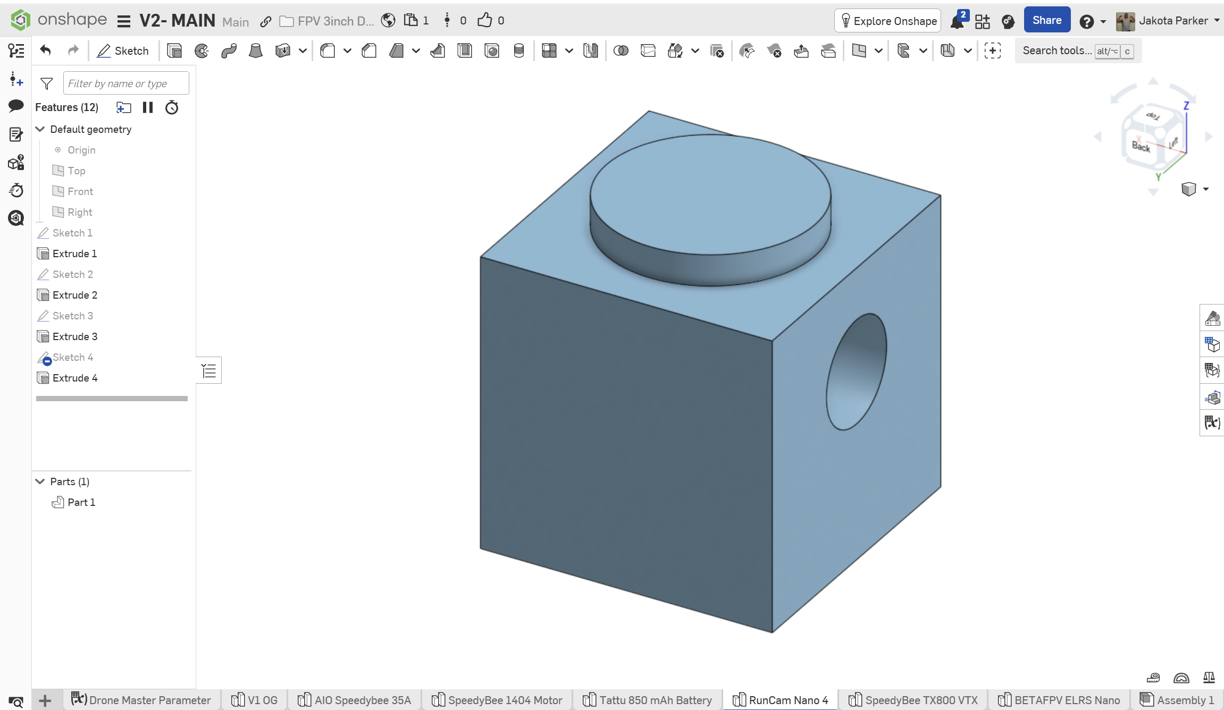
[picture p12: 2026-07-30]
media/7-30-26 RunCam Nano 4 Isometric.png

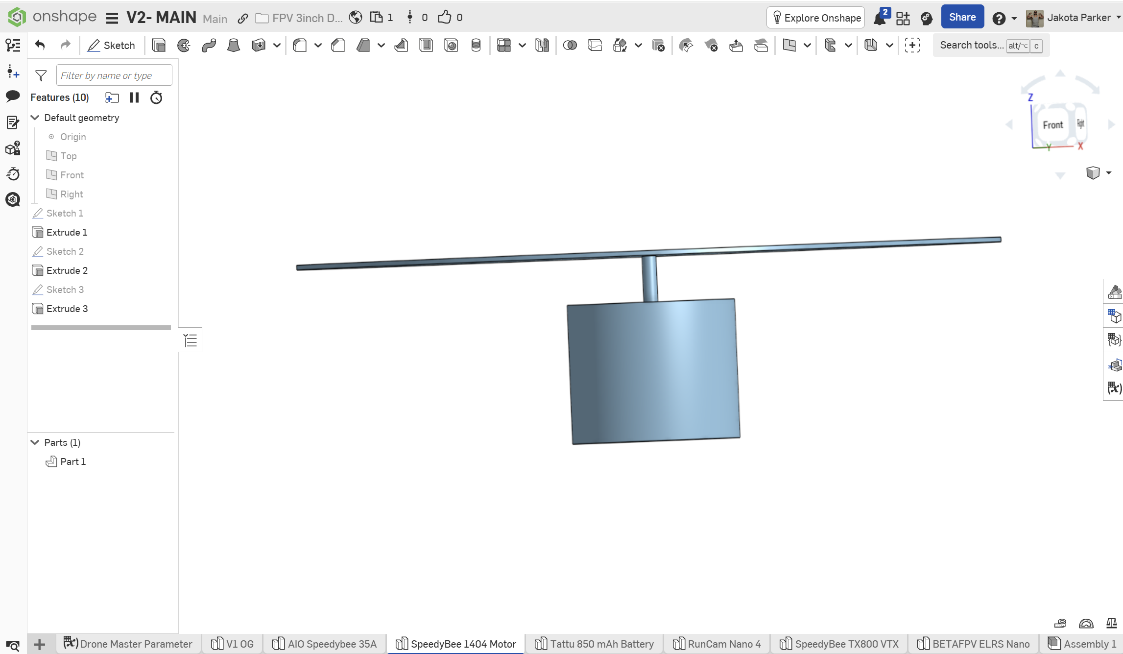
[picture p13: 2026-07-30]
media/7-30-26 SpeedyBee 1404 w.prop disc.png

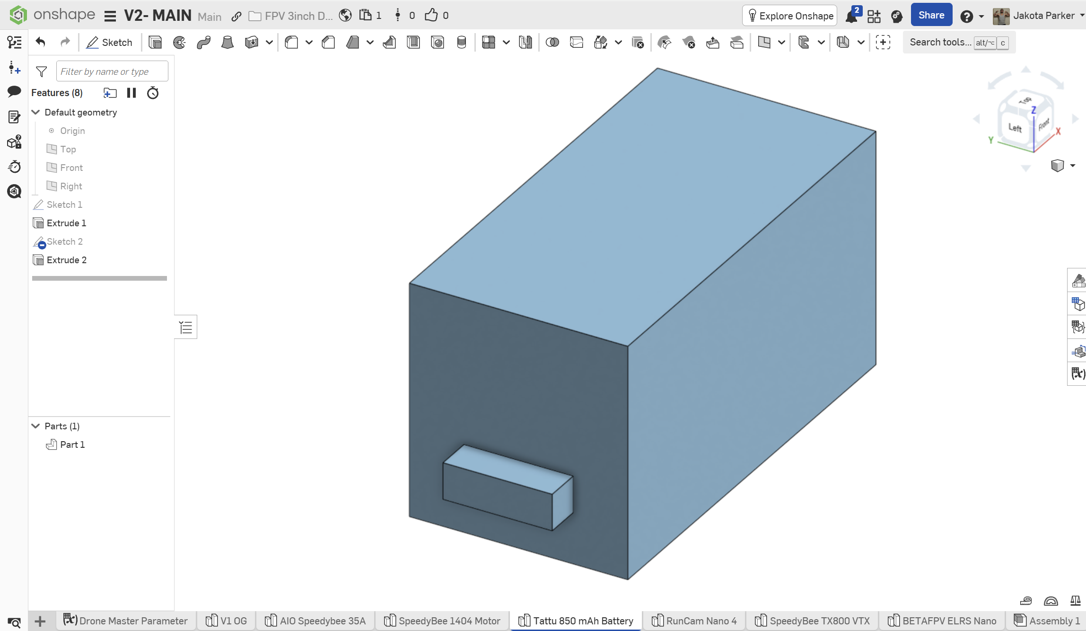
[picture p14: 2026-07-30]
media/7-30-26 Tattu Battery Isometric.png

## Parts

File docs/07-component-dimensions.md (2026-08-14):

# Purchased Components Inventory

This document contains the physical dimensions and verification status for every component used in the drone build.

## Measurement Status Legend

| Status | Description |
|---|---|
| Manufacturer Specification | Dimensions provided by the manufacturer. |
| AliExpress Listing | Dimensions taken from the product listing. |
| Estimated | Estimated dimensions before physical measurements. |
| Physically Verified | Measured with calipers after the component arrives. |

---

# Component Inventory

| Component | Manufacturer | Model | Qty | Length (mm) | Width (mm) | Height (mm) | Weight (g) | Mount Pattern | Hole Diameter | Important Dimensions / Notes | Measurement Source | Verified |
|---|---|---|-----|---|---|---|---|---|---|---|---|---|
| Motor | | | 4 | | | | 9 g | | | Diameter, shaft size, mounting-hole spacing, screw size | | ☐ |
| Flight Controller / AIO | | | 1 | | | | | | | Board dimensions, connector orientation | | ☐ |
| Camera | | | 1 | | | | | | | Lens size, mounting-hole spacing | | ☐ |
| Video Transmitter (VTX) | | | 1 | | | | | | | Antenna connector, mounting pattern | | ☐ |
| Receiver | | | 1 | | | | | | | Antenna arrangement | | ☐ |
| Antenna | | | 1 | | | | | N/A | N/A | Connector type, mounting method | | ☐ |
| Battery Connector (XT30/XT60) | | | 1 | | | | | N/A | N/A | Wire gauge, connector type | | ☐ |
| Propeller | | | 4 | | | | | N/A | N/A | Diameter, pitch, maximum sweep area | | ☐ |
| Battery | | | 1 | | | | | N/A | N/A | Capacity, dimensions, weight | | ☐ |
| Capacitor | | | 1 | | | | | N/A | N/A | Voltage, capacitance, diameter | | ☐ |
| Buzzer | | | 1 | | | | | | | Mounting method | | ☐ |
| GPS (Optional) | | | 1 | | | | | | | Connector location | | ☐ |
| Hardware / Screws | | | | | | | | | | Screw size, length, material | | ☐ |

---

# Motor Measurements

| Parameter | Value | Unit | Measurement Source | Verified |
|---|---|---|---|---|
| Motor Diameter | 18 | mm | Digital Caliper | X |
| Motor Height | 16.8 | mm | Digital Caliper | X |
| Shaft Diameter | 1.4 | mm | Digital Caliper | X |
| Mounting Hole Spacing | M2X7.9 | mm | Digital Caliper | X |
| Mounting Screw Size | M2 | | SpeedyBee | X |
| Motor Weight | 9.12 | g | SpeedyBee | X |

---

# Flight Controller / AIO Measurements

| Parameter | Value | Unit | Measurement Source | Verified |
|---|---|---|---|---|
| Board Length | 33 | mm | AliExpress | X |
| Board Width | 33 | mm | AliExpress | X |
| Board Height | 7 | mm | AliExpress | X |
| Mount Pattern | 25.5 x 25.5| mm | AliExpress | X |
| Hole Diameter | 2 | mm | AliExpress | X |
| USB Orientation | Type-C | | AliExpress | X |
| Weight | 10 | g | Scale | X |

---

# Camera Measurements

| Parameter | Value | Unit | Measurement Source | Verified |
|---|---|---|---|---|
| Width | 14 | mm | AliExpress | X |
| Height | 14 | mm | AliExpress | X |
| Depth | 14 | mm | AliExpress | X |
| Lens Diameter | M8 | mm | AliExpress | X |
| Mount Hole Spacing | Custom TPU enclosure 14mm gap | mm | AliExpress | X |
| Weight | 3 | g | Scale| X |

---

# Receiver Measurements

| Parameter | Value | Unit | Measurement Source | Verified |
|---|---|---|---|---|
| Length | 11| mm | AliExpress | X |
| Width | 18 | mm | AliExpress | X |
| Thickness | 12 | mm | AliExpress | X |
| Antenna Arrangement |IPEX1 |  | AliExpress | X |
| Weight | 2| g | Scale | X |

---

# Video Transmitter Measurements

| Parameter | Value | Unit | Measurement Source | Verified |
|---|---|---|---|---|
| Length | 28 | mm | AliExpress| X |
| Width | 28| mm | AliExpress | X |
| Height | 5.6 | mm | AliExpress | X |
| Mount Pattern | 20 X 20 M3 End to End 23| mm | Digital Caliper | X |
| Antenna Connector | MMCX | | AliExpress | X |
| Weight | 7 | g | Scale | X |

---

# Battery Measurements

| Parameter | Value | Unit | Measurement Source | Verified |
|---|---|---|---|---|
| Length | 59.7 | mm | Digital Caliper | X |
| Width | 30.4 | mm | Digital Caliper | X |
| Height | 32 | mm | AliExpress | X |
| Weight | 99 | g | Scale | X |
| Capacity | 850 | mAh | AliExpress | X |
| Cell Count | 4 | S | AliExpress | X |

---

# Propeller Measurements

| Parameter | Value | Unit | Measurement Source | Verified |
|---|---|---|---|---|
| Diameter | 75.5 | mm | Digital Caliper | X |
| Pitch | 1.5 | in | AliExpress | X |
| Maximum Sweep Diameter | 76.5 | mm | AliExpress | X |
| Weight | 1.18 | g | AliExpress | X |

---

# Notes

- Verify all critical dimensions using digital calipers before finalizing Frame V2.
- Update the CAD models if measured dimensions differ from the published specifications.
- Record any manufacturing tolerances or unexpected dimensional differences.
- Mark each component as **Physically Verified** only after direct measurement.
-   Record any manufacturing tolerances or unexpected dimensional
    differences.
-   Mark each component as **Physically Verified** only after direct
    measurement.

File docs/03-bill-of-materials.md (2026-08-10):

# 03 — Bill of Materials

**Version:** V1.0

**Status:** Frozen for Prototype V1

**Last Updated:** July 2026

Do not mark a component as selected until its dimensions, voltage, current rating, protocol, and mounting compatibility have been checked.

| Subsystem | Component | Candidate / Part Number | Qty | Selected? | Cost | Compatibility Notes |
|---|---|---:|---:|---|---:|---|
| Airframe | Custom Frame V1 | Onshape design | 1 | Prototype | TBD | Full print not validated |
| Propulsion | Brushless motor | SpeedyBee 1404 Motor | 4 | Yes | TBD | Match prop, voltage, mounting pattern |
| Propulsion | 3-inch propeller set | GemFan | 4 sets | Yes | TBD | Check shaft and frame clearance |
| Control | AIO | SpeedyBee AIO 35A | 1 | Yes | TBD | Check mounting, UARTs, ESC rating |
| Radio | ELRS Controller | Radiomaster T8L  | 1 | Yes | TBD | Match transmitter frequency |
| FPV | FPV camera | RunCam Nano 4 | 1 | Yes | TBD | Check voltage and physical dimensions |
| FPV | Video transmitter | SpeedyBee TX800 | 1 | Yes | TBD | Check voltage, output, mounting |
| FPV | VTX antenna | SpeedyBee TX800 | 1 | Yes | TBD | Match connector and frequency |
| Power | LiPo battery | Tattu 850 mAh | 2+ | Yes | TBD | Match cell count and connector |
| Power | Battery connector | TBD | 1 | Yes | TBD | Match current demand |
| Hardware | Screws / standoffs | TBD | Set | Yes | TBD | Match frame and electronics |
| Safety | Smoke stopper | ViFly 2 | 1 | Yes | TBD | Required for first power-up |
| Safety | LiPo-safe charging/storage gear | ToolKit RC | 1 | Yes | TBD | Required for battery handling |

## BOM Decision Checklist

Before selecting a part, confirm:

- Physical dimensions
- Mounting-hole pattern
- Weight
- Input voltage
- Current rating
- Connector type
- Radio/video protocol
- Firmware support
- Seller reputation
- Replacement availability
- Total system compatibility

## Component Selection

| Component | Selected Part | Qty | Vendor | Status | Cost |
|---|---|:---:|---|:---:|-----:|
| Flight Controller (AIO) | SpeedyBee F405 AIO 35A Bluejay (No Case) | 1 | AliExpress | Delivered | $71.23 |
| Motors | SpeedyBee 1404 V2 4600KV | 4 | SpeedyBee | Ordered | $55.98 |
| Propellers | Gemfan 3016 | 4 sets (16 props) | Gemfan | Delivered | $8.29 |
| FPV Camera | RunCam Nano 4 Mini | 1 | RunCam | Ordered | $29.27 |
| Video Transmitter | SpeedyBee TX800 | 1 | SpeedyBee | Delivered | $58.42 |
| ELRS Receiver | BETAFPV ELRS Nano Receiver (2.4 GHz) | 1 | BETAFPV | Ordered | $15.10 |
| Battery | Tattu R-Line 850mAh 4S 95C XT30 | 2 | Tattu | Delivered | $44.50 |
| FPV Goggles | EACHINE EV800D | 1 | BETAFPV | Ordered | $166.58 |
| Radio Controller | RadioMaster T8L ELRS | 1 | RadioMaster | Ordered | $40.72 |
| Smoke Stopper | VIFLY Smoke Stopper | 1 | VIFLY | Delivered | $19.27 |
| Battery Charger | ToolkitRC C6 50W AC | 1 | ToolkitRC | Delivered | $41.10 |
| VTX Antenna | Included SpeedyBee MMCX Antenna | 1 | SpeedyBee | Included with TX800 | $0 |
| XT30 Pigtail | 16 AWG Silicone Wire | 5 | Generic | Ordered | $10 |
| Battery Strap | 15 × 200 mm Kevlar Strap | 2 | Generic | Ordered | $9.77 |
| Charging Adapter | XT60 Female → XT30 Male | 1 | Generic | Delivered | $2.30 |
| Heat Shrink | XHF UL Listed 225 Pcs Length 3.45 | 1 Kit | XHF | Delivered | $2.66 |
| Capacitor | 470 µF Low ESR 25V | 5 | Generic | Delivered | $6.43 |
Total Extended Cost (Post-Tax) : $ 581.62
## Mechanical & Electrical Specifications

| Component | Dimensions | Weight | Voltage | Mounting | Interface |
|---|---:|---:|---:|---|---|
| SpeedyBee F405 AIO | 33 × 33 mm | 8.9 g | TBD | 25.5 × 25.5 mm | USB, UART, Motor Outputs |
| SpeedyBee 1404 V2 | 14 × 14 mm | TBD | 4600 KV | 9 × 9 mm M2 | 3-Phase Motor Wires |
| Gemfan 3016 | 3 in | TBD | N/A | 1.5 mm Shaft | N/A |
| RunCam Nano 4 Mini | 14 × 14 mm | TBD | TBD | 14 mm Nano | Analog Video |
| SpeedyBee TX800 | 28 × 28 mm | 3.3 g | 3.7-5 V | TPU Mount / Tape | Video + UART |
| ELRS Nano Receiver | 12 × 19 mm | 0.7 g | 5 V | Heat Shrink / Tape | CRSF + UART |
| Tattu R-Line Battery | TBD | 80–85 g | 14.8 V (4S) | Battery Strap | XT30 |
| EACHINE EV800D | TBD | TBD | Internal Battery | Head Strap | 5.8 GHz Analog |
| RadioMaster T8L | TBD | TBD | TBD | Handheld | ELRS 2.4 GHz |
| VIFLY Smoke Stopper | TBD | TBD | TBD | Inline | XT30 / XT60 |
| ToolkitRC C6 | TBD | TBD | AC Input | Bench | XT60 + Balance Port |
| Rush Cherry II | TBD | TBD | Passive | U.FL | 5.8 GHz RF |
| XT30 Pigtail | TBD | TBD | TBD | Soldered | XT30 |
| Battery Strap | 15 × 200 mm | TBD | N/A | Mechanical | Strap |
| Charging Adapter | TBD | TBD | N/A | Inline | XT60 ↔ XT30 |
| Heat Shrink | Various | TBD | N/A | Heat Applied | Insulation |
| Capacitor | TBD | TBD | 25 V | Soldered | Power Filter |

### Propulsion Verification

- Motor: SpeedyBee 1404 V2 4600KV
- Propeller: Gemfan 3016
- Battery: 4S LiPo
- Maximum thrust per motor: 431 g
- Maximum combined thrust: 1,724 g
- Target all-up weight: ≤250 g
- Estimated thrust-to-weight ratio at 250 g: 6.9:1
- ESC current verification: Pending
- Compatibility status: Verified for thrust

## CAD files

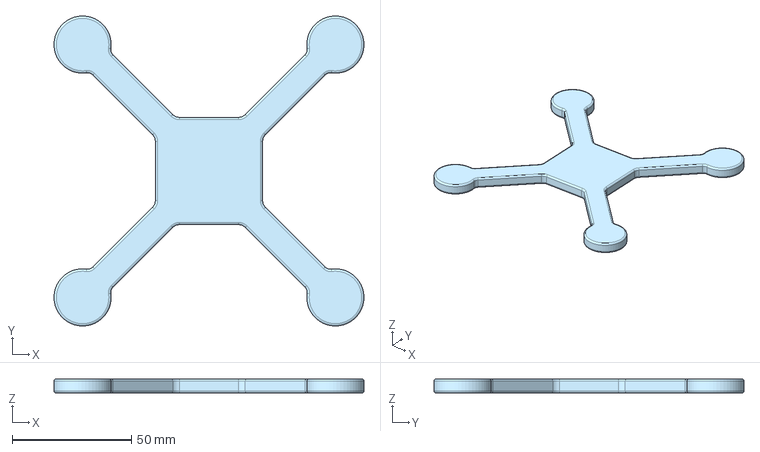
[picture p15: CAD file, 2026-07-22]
cad/frame-v1/frame-v1.step
130.0 x 130.0 x 6.00 mm

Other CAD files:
cad/frame-v1/frame-v1.stl

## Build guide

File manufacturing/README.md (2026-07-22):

# Manufacturing

This directory records how each physical revision was produced.

Do not rely on memory for slicer settings. Every print test should record:

- Printer
- Material
- Nozzle size
- Nozzle temperature
- Bed temperature
- Layer height
- Line width
- Wall count
- Top and bottom layers
- Infill
- Print speed
- Cooling
- Supports
- Build-plate adhesion
- Estimated and actual print time
- Result

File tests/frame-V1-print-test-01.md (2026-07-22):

# Frame V1 Print Test 01

## Test Information

- Date:
- Frame revision: V1
- Printer: Ender 3 V2
- Material: PLA+
- Slicer: Cura

## Objective
Complete a full print of frame V1 and evaluate print quality, dimensional accuracy, layer adhesion, warping, and structural integrity.

## Print Settings
Reference:
'manufacturing/print-profiles/frame-v1-print-settings.md'

## Expected Result

The frame should complete without:

- Missing extrusion
- Major warping
- Layer separation
- Detached sections
- Severe stringing
- Incorrect dimensions
- Weak or flexible motor arms

## Actual Result

- Print completed: Not tested
- Print duration:
- Failure point:
- Warping:
- Layer adhesion:
- Surface quality:
- Infill quality:
- Structural condition:

## Result
**Staus: NOT TESTED**

## Next Action

Complete the full print while the printer can be periodically supervised.

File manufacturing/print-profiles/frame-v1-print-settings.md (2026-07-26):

# Frame V1 Print Settings

## Printer

- Printer: Ender 3 V2
- Build surface: Glass
- Nozzle diameter: 0.4 mm
- Firmware / leveling method: Manual mesh leveling

## Material

- Material: PLA+
- Brand: SUNLU
- Color: Black
- Filament condition: New

## Cura Settings

| Setting | Value |
|---|---|
| Layer height | 0.2 mm |
| Initial layer height | 0.2 mm |
| Line width | 0.4 mm |
| Wall line count | 3 |
| Top layers | 5 |
| Bottom layers | 5 |
| Infill percentage | 35% |
| Infill pattern | Gyroid |
| Printing temperature | 210 C |
| Build plate temperature | 60 C |
| Print speed | 40 mm/s |
| Initial layer speed | 15 mm/s |
| Infill speed | 35 mm/s |
| Travel speed | 120 mm/s |
| Fan speed | 100% |
| Supports | TBD |
| Build plate adhesion | Skirt |
| Estimated print time | 16 hrs |

## Print Result

- Date: 7/20/2026
- Completed: No
- Failure point: Nozzle
- Surface quality: Jagged lines
- Layer adhesion: Good
- Warping: Mild
- Stringing: Mild
- Dimensional issues: N/A
- Corrective action: Manually increased the nozzle temperature to 220 degree, seemed to make materail flow more smoothly. Need to reduce travel speed, increase nozzle temp, and really reduce
  infill speed.

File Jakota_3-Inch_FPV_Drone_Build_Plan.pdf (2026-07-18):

3-Inch FPV Drone Build Plan | Jakota Parker | Page 1

BUILD MANUAL

# 3-Inch 4S FPV Drone

A staged plan for designing, printing, soldering, configuring, testing, and flying your first custom mini quadcopter.

Target | Selected architecture
Airframe | 3-inch replaceable 3D-printed prototype frame
Power system | 4S LiPo; 1404 motors; 3,500-4,000KV
Electronics | 25.5 x 25.5mm AIO flight controller + 4-in-1 ESC
Control link | ExpressLRS 2.4GHz
Video | Analog 5.8GHz FPV
Firmware | Betaflight
Weight objective | Under 250g including battery
Mission | Build a safe, repairable first FPV aircraft while documenting the engineering decisions as a portfolio project.

# Prepared for Jakota Parker

### Version 1.0 | July 2026

Core rule: Do not install propellers during soldering, firmware configuration, receiver setup, or motor testing.

# Build Roadmap

Complete each gate before moving forward. This prevents incompatible purchases and makes troubleshooting manageable.

Phase | Outcome | Gate to continue
1. Define | Architecture and project folder | Target specification recorded
2. Control gear | Radio, goggles, simulator | Radio works in simulator
3. Electronics | Compatibility-checked bill of materials | All dimensions and voltage ratings match
4. Frame | Printed fit-check prototype | Props and hardware clear the frame
5. Assembly | Dry fit and wiring map | Every component has a secure location
6. Solder | Electronics connected | No short; smoke-stopper test passes
7. Configure | ELRS and Betaflight operational | Controls, OSD, failsafe verified
8. Bench test | Correct motor map and direction | All tests pass with props removed
9. Flight | Controlled hover and inspection | No heat, cracks, or control problems

# Project documentation structure

- 01-requirements: goals, weight limit, selected architecture
- 02-frame: STL, CAD, slicer profile, revisions
- 03-electronics: datasheets, BOM, wiring diagram
- 04-betaflight: backups, screenshots, configuration notes
- 05-build-log: dated photographs and assembly notes
- 06-test-results: weights, hover results, failures, improvements
Portfolio habit | Record why you chose each part, not only what you purchased. Engineering judgment is part of the project.

# Component Plan and Compatibility Rules

Recommended architecture: separate AIO FC/ESC, ELRS receiver, analog VTX, and camera. Most true 5-in-1 boards are intended for low-power 1S whoops and should not be assumed suitable for this 4S three-inch build.

Component | Required specification | Qty
AIO FC/ESC | F405; 25.5 x 25.5mm mount; 3-6S; 25A minimum, 35-40A preferred | 1
Motors | 1404; about 3,500-4,000KV for 4S; verify mounting and shaft | 4 + optional spare
Receiver | Serial ExpressLRS 2.4GHz nano receiver | 1
Camera | Analog nano camera; typically 14 x 14mm | 1
VTX | Analog 5.8GHz; switchable 25-400mW | 1
VTX antenna | Correct U.FL/MMCX connector; secured away from props | 1
Propellers | 3-inch tri-blade; correct shaft/fastening type | 6+ sets
Batteries | 4S 650mAh initially; XT30 | 3-5
Power lead | XT30 silicone-wire pigtail | 1 + spare
Capacitor | Low-ESR, approximately 470uF, 25V | 1
Buzzer | Small active or self-powered FPV buzzer | 1
Hardware | M2 screws, nuts, standoffs, washers, straps | Assortm ent

# Purchase order

Batch | Buy | Why
1 | RadioMaster Pocket ELRS, two 18650 cells, analog goggles, simulator, smoke stopper, LiPo storage, multimeter | Practice and prepare before the airframe exists
2 | AIO, motors, ELRS receiver, camera, VTX, antenna, props, XT30, capacitor, buzzer, M2 hardware | Buy only after frame dimensions are locked
3 | 4S batteries, quality balance charger, spare props, spare motor | Finalize after power-system compatibility is confirmed

# Frame Design and Printing

Print a dimensional mock-up first. PLA+ is acceptable for fit checking and gentle early testing, but a fully printed frame will be less rigid and crash-resistant than carbon fiber.

Design feature | Starting requirement
Wheelbase | Approximately 130-145mm diagonal motor-to-motor
Prop clearance | Full 3-inch prop circles must not overlap frame, wires, or antenna
Motor mounting | Match exact motor hole pattern; commonly 9 x 9mm or 12 x 12mm
Electronics mounting | 25.5 x 25.5mm AIO pattern using M2 soft mounts
Camera | 14 x 14mm nano mount with protected lens and adjustable angle
Battery | Top mount near center of gravity; strap slots with rounded edges
Serviceability | Accessible USB port; replaceable/quick-to-reprint main structure

# Starting slicer settings

Parameter | Starting point
Material | PLA+ for mock-up; PETG, nylon, or tougher material for flight version
Layer height | 0.20mm
Walls | 5-7
Top/bottom | 6-8 layers
Infill | 80-100%; gyroid or cubic
Orientation | Arms flat in XY plane
Adhesion | Clean glass first; add 5-8mm brim for long arms; glue only if needed
Printer check | Watch the complete first layer. Stop if the nozzle scrapes glass, filament does not flow, or lines remain round and separate. The first layer should be slightly flattened and joined.

# Frame gate checklist

- ■ Motor holes match actual motors
- ■ AIO holes match actual board
- ■ No motor screw can touch windings
- ■ Three-inch prop circles clear the frame
- ■ USB port remains accessible
- ■ Camera and antennas are protected
- ■ Battery sits close to the center of gravity

# Dry Fit and Wiring Plan

Do not solder until every component has a planned location and wire route. Photograph the dry fit before disassembling it.

- ■ Temporarily mount all four motors
- ■ Place AIO on soft M2 gummies with orientation arrow noted
- ■ Position camera and confirm field of view
- ■ Separate receiver antenna from VTX antenna and high-current wiring
- ■ Place VTX where it receives airflow
- ■ Route XT30 lead away from propellers
- ■ Place battery and check balance
- ■ Install props only for clearance, then remove them

# Power and signal layout

Connection | Route
Battery power | 4S battery -> XT30 -> capacitor/AIO battery pads
Motors | AIO motor outputs M1-M4 -> three wires per motor
ELRS receiver | 5V, GND, receiver TX -> FC RX, receiver RX -> FC TX
Video camera | Camera power/GND; camera video -> FC video-in/CAM
VTX | Regulated power/GND as specified; FC video-out -> VTX video; control wire -> supported UART/pad
Buzzer | FC buzzer positive/negative pads according to board manual
UART rule | For serial devices, TX and RX cross: device TX connects to flight-controller RX, and device RX connects to flight-controller TX.
Power warning | Use the exact manual for the selected AIO, camera, and VTX. Never assume every 5V, 9V, battery-voltage, camera, or video pad behaves like one from another board.

# Soldering and First Power-Up

Required bench equipment: flux, suitable electronics solder, silicone wire, heat shrink, brass tip cleaner, tweezers, magnification, multimeter, PCB holder, heat-resistant mat, fume extraction, and a smoke stopper.

Absolute rule | Never solder with a LiPo connected. Never connect a freshly soldered aircraft directly to a battery for its first test.

# Soldering order

Ste p | Action | Test gate
1 | Practice on a spare board; form shiny, compact joints | No bridges or loose strands
2 | Tin XT30 pads, leads, and capacitor legs | Correct polarity confirmed
3 | Install capacitor and XT30 pigtail | Multimeter shows no hard short
4 | First battery power through smoke stopper | Board boots normally
5 | Disconnect battery; solder motor wires | Visual inspection passes
6 | Smoke-stopper power test again | No trip or excessive heat
7 | Solder receiver, camera, VTX, and buzzer one system at a time | Test after each subsystem
8 | Inspect under magnification; add strain relief and heat shrink | No exposed conductors or weak joints

# Pre-power checklist

- ■ Propellers removed
- ■ Battery polarity checked twice
- ■ Capacitor polarity correct
- ■ No solder bridges
- ■ No loose wire strands
- ■ Positive-to-ground check completed
- ■ Antennas connected before powering VTX
- ■ Smoke stopper installed

# Radio, ExpressLRS, and Betaflight

Use a unique ExpressLRS binding phrase on both the transmitter and receiver. In Betaflight, a serial ELRS receiver normally uses Serial RX on its assigned UART and CRSF as the receiver protocol.

# Configuration sequence

- ■ Install/open the current Betaflight application
- ■ Connect by USB with props removed
- ■ Save a configuration backup before changes
- ■ Confirm the 3D model follows the aircraft movement correctly
- ■ Set board alignment if the AIO is rotated
- ■ Enable Serial RX on the receiver UART
- ■ Select serial receiver and CRSF
- ■ Verify roll, pitch, yaw, and throttle direction
- ■ Verify endpoints are approximately 1000 / 1500 / 2000
- ■ Assign ARM and BEEPER switches
- ■ Configure OSD: voltage, average cell voltage, flight time, link quality, warnings
- ■ Configure VTX table and legal power/channel
- ■ Verify battery-voltage reading
- ■ Configure flight-controller failsafe to stop the aircraft on link loss

Safety behavior Test failsafe with propellers removed: arm under controlled bench conditions, switch off the transmitter, and confirm the flight controller detects link loss and stops motor outputs.

# Do not tune yet

Begin with the AIO manufacturer defaults or a documented preset appropriate for the build. Do not change PIDs and filters randomly before establishing a safe hover and collecting evidence.

# Motor Test, Final Assembly, and First Flight

Motor testing is performed with every propeller removed and the frame secured.

# Motor test

- ■ Use Betaflight Motors tab only after acknowledging the warning
- ■ Spin one motor at a time at very low power
- ■ Verify motor number and physical location
- ■ Verify configured rotation direction
- ■ Correct direction with the supported ESC configurator
- ■ Listen for grinding or intermittent operation
- ■ Stop if a motor or ESC heats rapidly

# Final assembly

- ■ Confirm props-in or props-out configuration
- ■ Install each prop with leading edge facing the configured rotation
- ■ Secure all wires and antennas away from props
- ■ Add XT30 strain relief
- ■ Tighten screws without contacting motor windings
- ■ Weigh aircraft with battery and record result
- ■ Inspect printed frame for layer separation

# First-flight procedure

Stage | Action
Site | Open field; clear of people, animals, vehicles, structures, and obstacles
Before power | Radio on; correct model selected; goggles on; antennas installed
Power | Connect full battery; confirm video, OSD, receiver link, and warnings
Hover | Arm from behind; hover 2-3 feet for 20-30 seconds; land and disarm
Inspection | Disconnect battery; inspect frame and solder joints; feel motors/electronics for abnormal heat
Progression | Only repeat or extend flight if the first inspection is clean

# Build Log, Safety, and Next Iteration

Record these values for every frame or electronics revision.

Measurement | Record
Frame revision / material | ____________________________
Dry weight / battery weight / takeoff weight | ____________________________
Motor / KV / propeller | ____________________________
Battery / connector | ____________________________
AIO firmware and Betaflight version | ____________________________
Hover time and landing voltage | ____________________________
Motor temperatures by touch or instrument | ____________________________
Cracks, vibration, video noise, control issues | ____________________________
One change for next revision | ____________________________

# LiPo and operating safety

- Use a quality balance charger and the correct LiPo cell count and charge current.
- Charge on a nonflammable surface and remain present. Store batteries appropriately; do not use damaged or swollen packs.
- Do not power a VTX without its antenna unless its manufacturer explicitly permits it.
- Keep propellers removed whenever the drone is connected to a computer or being serviced.
- For recreational flight in the United States, complete the FAA TRUST test and follow current FAA airspace and operating requirements.

# Reference links

- Betaflight setup: https://betaflight.com/docs/wiki/getting-started/setup-guide
- Betaflight failsafe: https://betaflight.com/docs/wiki/guides/current/Failsafe
- ExpressLRS binding: https://www.expresslrs.org/quick-start/binding/
- FAA recreational flyers: https://www.faa.gov/uas/recreational_flyers
- RadioMaster Pocket: https://radiomasterrc.com/products/pocket-radio-controller-m2
- Example AIO specification: https://www.speedybee.com/speedybee-f405-aio-40a-bluejay-25-5x25-5-3-6s-flight-controller/
Next action | Print and measure the mock frame. Before buying the electronics, verify the exact frame STL, AIO listing, motor listing, motor-hole pattern, shaft/prop attachment, and expected component placement.

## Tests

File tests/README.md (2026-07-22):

# Tests

Create a separate file for every meaningful test.

## Suggested Test Files

- `frame-v1-cad-review.md`
- `frame-v1-print-test-YYYY-MM-DD.md`
- `frame-v1-dimensional-inspection.md`
- `frame-v1-component-fit.md`
- `electronics-continuity-test.md`
- `smoke-stopper-test.md`
- `motor-direction-test.md`
- `first-hover-test.md`

Every test record should include:

- Date
- Revision
- Objective
- Setup
- Procedure
- Expected result
- Actual result
- Pass/fail decision
- Photos or evidence
- Problems
- Corrective action

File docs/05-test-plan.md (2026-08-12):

# 05 — Test Plan

Testing progresses from the lowest-risk level to the highest-risk level. Do not skip directly to flight testing.

## Test Sequence

### T1 — CAD Review

Check:
- Motor-hole spacing
- Flight-controller-hole spacing
- Propeller clearance
- Camera dimensions
- Battery dimensions
- Wire-routing space
- USB access
- Fastener access

Result: PASS

### T2 — Print Completion

Record:
- Material
- Nozzle diameter
- Nozzle temperature
- Bed temperature
- Layer height
- Wall count
- Infill percentage and pattern
- Print speed
- Supports
- Print duration
- Failure location, if any

Result: `PASS 

### T3 — Dimensional Inspection

Measure:
- Overall wheelbase
- Motor-hole spacing
- Flight-controller-hole spacing
- Arm thickness
- Electronics-bay dimensions
- Camera-mount dimensions
- Battery area
- Propeller clearance

Result: `PASS / FAIL / NOT TESTED`

### T4 — Component Fit

Check every component without soldering where practical.

Result: `PASS / FAIL / NOT TESTED`

### T5 — Structural Bench Check

Check:
- Arm stiffness
- Layer separation
- Cracks
- Fastener pull-through
- Motor-mount deformation
- Battery retention

Result: `PASS / FAIL / NOT TESTED`

### T6 — Electrical Inspection

With the battery disconnected:
- Inspect solder joints.
- Test continuity.
- Confirm polarity.
- Check for shorts.
- Verify connector orientation.

Result: `PASS / FAIL / NOT TESTED`

### T7 — Smoke-Stopper Power Test

- Remove propellers.
- Use a smoke stopper.
- Watch for heat, smoke, odor, or abnormal current behavior.
- Disconnect immediately if abnormal behavior occurs.

Result: `PASS / FAIL / NOT TESTED`

### T8 — Betaflight Bench Test

- Verify board connection.
- Confirm gyro response.
- Verify receiver channels.
- Configure failsafe.
- Confirm motor order.
- Confirm motor direction.
- Save configuration backup.

Result: `PASS / FAIL / NOT TESTED`

### T9 — Controlled Hover

- Inspect aircraft.
- Use a clear open test area.
- Begin with a low hover.
- Land immediately if oscillation, overheating, signal loss, or structural problems appear.

Result: `PASS / FAIL / NOT TESTED`

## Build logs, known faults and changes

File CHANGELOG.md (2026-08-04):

# Changelog

All notable design, manufacturing, electronics, firmware, and testing changes should be recorded here.

## V2 Frame Development 8/3

### Added
- Created parametric V2 master layout
- Created simplified component envelope models
- Designed V2 center body, arms, and motor pads
- Added SpeedyBee 1404 motor mounting pattern
- Added SpeedyBee F405 AIO mounting pattern
- Created assembly-level component packaging study
- Verified preliminary propeller and component clearances

### In Progress
- Battery mounting
- Camera mounting
- TX800 mounting
- ELRS receiver retention
- Antenna routing
- Structural refinement
## Unreleased

### Frame V1

#### Added
- Initial 3-inch mini FPV drone repository structure.
- Initial Frame V1 CAD model created in Onshape.
- Initial project-definition and system-architecture documents.
- Initial Cura print profile.
- Frame V1 .stl manufacturing export.
- Frame V1 .step CAD exchange export.

#### Not Yet Validated
- Full-frame print completion
- Dimensional accuracy
- Motor mounting pattern
- Flight-controller mounting pattern
- Propeller clearance
- Battery placement
- Structural durability
- Electronics fit
- Flight performance

## Revision Entry Template

### Frame VX — YYYY-MM-DD

#### Changed
- 

#### Reason
- 

#### Test Result
- 

#### Next Action
-

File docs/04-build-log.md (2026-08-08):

# 04 — Build Log

## Entry Template

### YYYY-MM-DD — Activity Title

**Phase:**  
**Revision:**  
**Goal:**  

#### Work Completed
- 

#### Observations
- 

#### Problems
- 

#### Measurements
- 

#### Decisions
- 

#### Files Added
- 

#### Next Action
- 

---

## 2026-07-22 — Repository and Documentation Setup

**Phase:** Step 1 — Define the Project  
**Revision:** Frame V1  
**Goal:** Establish the project repository and document the current design state.

#### Work Completed
- Created the initial repository architecture.
- Documented project scope, requirements, system architecture, BOM structure, build-log format, and test structure.
- Classified Frame V1 as an unvalidated CAD prototype.

#### Observations
- Frame V1 has been completed in Onshape.
- A complete supervised print has not yet been performed.

#### Problems
- Print validation remains incomplete because the printer has not been continuously supervised for the full run.

#### Next Action
- Add the Onshape link.
- Export STL and STEP versions.
- Record Cura settings.
- Complete and document a supervised full print.

## 2026-07-27 — Component Selection Completed

**Phase:** Step 2 — Complete full BOM  
**Revision:** Frame V1  
**Goal:** Establish the project BOM

#### Work Completed
- Finalized the V1 component list.
- Verified the analog video and ELRS radio architecture.
- Confirmed the SpeedyBee F405 AIO dimensions as 33 × 33 × 8 mm.
- Confirmed the 25.5 × 25.5 mm AIO mounting pattern.
- Confirmed the 9 × 9 mm M2 motor mounting pattern.
- Verified a maximum combined propulsion thrust of 1,724 g using the selected 1404 4600KV motors, Gemfan 3016 propellers, and 4S power.
- Calculated the current pre-tax project cost as approximately $431.

#### Next Action
- Update the Onshape frame for mechanical integration.

## 2026-07-28 — Ordered every electronic component required for the drone.

#### Work Completed
- Final BOM
- Compatibility verification
- Flight controller selection
- Motor selecetion
- Propeller selection
- Camera selection
- VTX selection
- Receiver selection
- Goggles
- Radio
- Charger
- Batteries

Total Project cost: $568.28

#### Next Action
- Mechanical integration and update of frame in Onshape

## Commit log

2026-07-26 Create frame-v1-mini-print-settings
2026-07-26 Update frame-v1-mini-print-settings
2026-07-30 Rename SppedyBee 1404 w.prop disc.png to 7-30-26 SpeedyBee 1404 w.prop disc.png
2026-07-30 Rename Tattu Battery Isometric.png to 7-30-26 Tattu Battery Isometric.png
2026-08-12 Create frame-v2-print-settings
2026-08-12 Update frame-v2-print-settings
